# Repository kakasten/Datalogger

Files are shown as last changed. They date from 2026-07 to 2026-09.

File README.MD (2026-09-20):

# 🎲 Distributed Data Acquisition Platform for Race Vehicles

> A modular, scalable, engineering-driven architecture for high-performance vehicle instrumentation.







---

## 📖 Overview

This project is the development of a **distributed data acquisition platform** for race vehicles, designed to provide a modular, scalable, and easy-to-maintain architecture — capable of evolving continuously alongside the team's needs.

Built for **Formula SAE** vehicles, the system acquires data from analog, digital, frequency, and CAN sensors, transmits the information over a **CAN** network, and centralizes logging, processing, and telemetry in the Master module.

Unlike traditional systems, which centralize all instrumentation in a single acquisition unit, this platform adopts an architecture composed of one **Master module** and **multiple Slave modules**, distributed throughout the vehicle and placed close to the sensors they monitor.

**Key features:**

- ✅ Distributed acquisition
- ✅ CAN Bus communication
- ✅ Modular hardware
- ✅ Local data logging
- ✅ Telemetry support
- ✅ Fault isolation
- ✅ Expandable architecture

> More than a conventional datalogger, this is an open hardware, firmware, and documentation ecosystem, built to grow alongside the team.

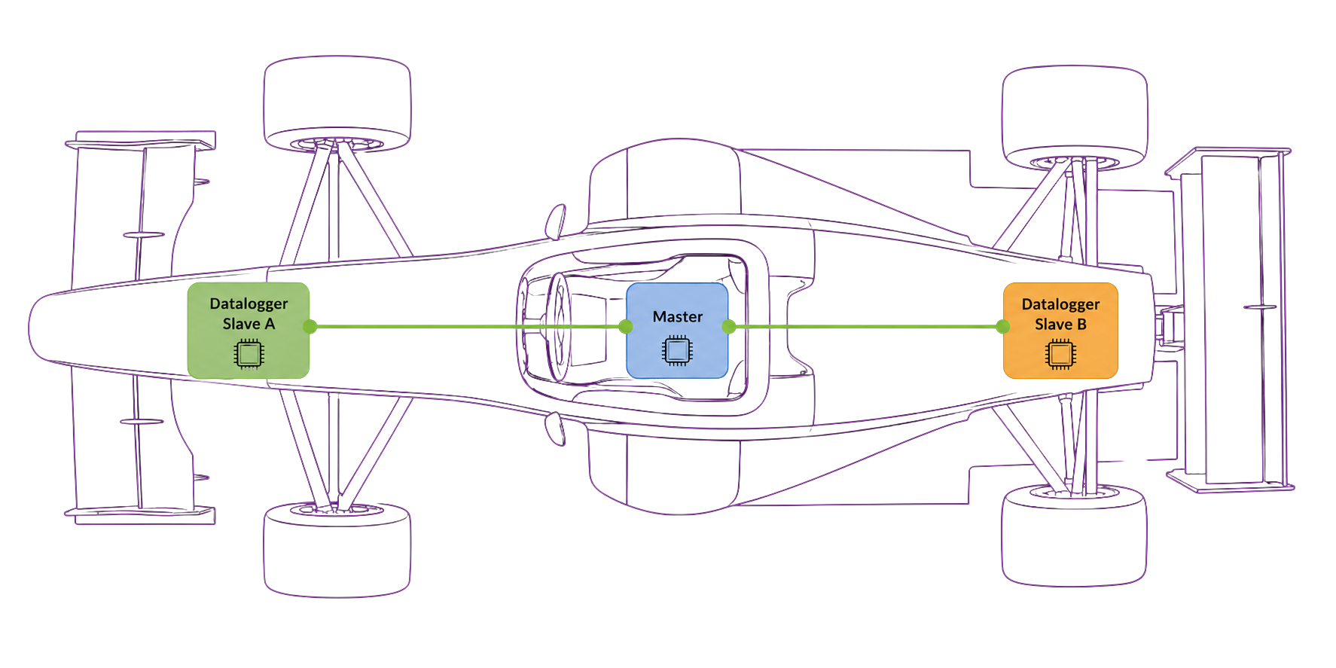
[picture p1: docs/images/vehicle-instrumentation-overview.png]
Vehicle Instrumentation Overview


---

## 🎯 The Problem We Solve

Centralized acquisition systems have well-known limitations in race vehicles:

- **Long, complex wiring harnesses**, with dozens of meters of cable running across the vehicle to a single central unit
- **High susceptibility to electromagnetic noise**, since low-amplitude analog signals must travel long distances before being conditioned
- **Difficult maintenance and expansion**, since every new sensor requires running a new cable to the central unit
- **Low scalability**, since expansion capacity is limited by the number of physical inputs on the central unit

Our approach solves these problems by **bringing processing to the sensor**, rather than the other way around.

---

## 🧩 System Architecture

### Selected Processing Units

The current hardware definition uses the following processing units:

| System role | Component | Responsibility |
| --- | --- | --- |
| Master | **Milk-V DUO S** (MPU) | High-level processing, data logging, telemetry, and system management |
| Slave | **STM32G431C8T6TR** (MCU) | Local sensor acquisition, signal processing, and CAN communication |

The platform is organized into two core functional blocks:

### 🔹 Master Module

The Master module is the platform's **central management point**. Its responsibilities include:

- Coordinating communication between the modules distributed across the vehicle
- Synchronizing data acquisition across all Slave modules
- Storing the data logged during vehicle operation
- Making data available to external analysis and development tools

The Master's architecture is designed to be **independent of specific implementation technologies** — allowing different software solutions, operating systems, communication protocols, or storage formats to be adopted as the project evolves, without compromising the platform's overall organization.

In the current implementation, the Master runs on the **Milk-V DUO S**, the selected **MPU (Microprocessor Unit)**, using an **RTOS (Real-Time Operating System)** as its software framework, responsible for coordinating logging, processing, and telemetry tasks.

### 🔹 Slave Modules

Slave modules are responsible for **local acquisition** of signals coming from the sensors. Close to the signal source, each module performs:

- Signal conditioning and filtering
- Analog-to-digital conversion
- Initial data processing
- Delivery of processed data to the vehicle's communication network

Each Slave is built around the **STM32G431C8T6TR**, the selected **MCU (Microcontroller Unit)**, responsible for local acquisition and for communicating over the **CAN** bus, which connects all modules to the Master.

Each module can be **specialized** according to the type of signal it needs to acquire:

| Module Type | Application |
| --- | --- |
| High-precision analog inputs | Pressure, temperature, potentiometer sensors |
| Digital inputs | On/off signals, buttons, limit switches |
| Timer capture | Wheel speed, RPM |
| Inertial sensors (IMU) | Acceleration, gyroscope |
| Suspension position | Vertical travel, suspension stroke |
| Custom modules | Application-specific sensors |

This specialization allows **hardware to be optimized for each module's function**, reducing cost, simplifying the electronic design, and increasing overall system reliability.

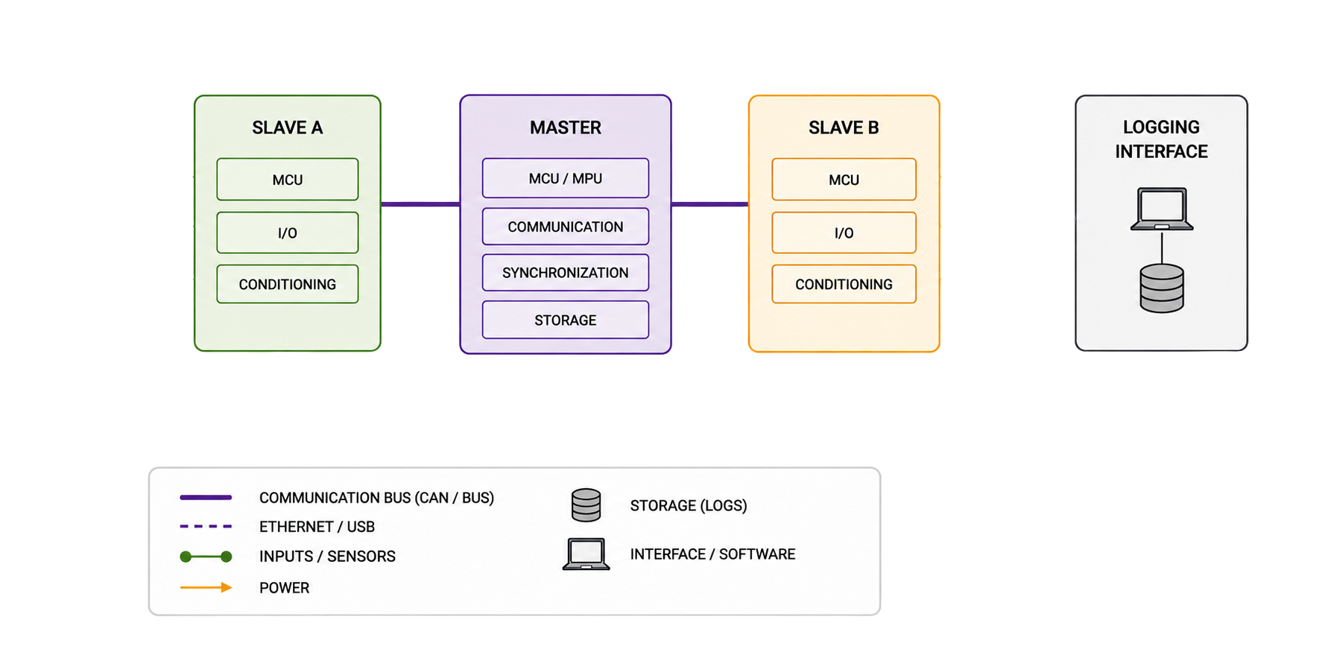
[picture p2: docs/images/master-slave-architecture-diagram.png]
Master and Slave Module Architecture Diagram


### 🔄 Communication Topology (High-Level View)

```text
                              ┌────────────────────────────┐
                              │           Master           │
                              │            MPU             │
                              │     RTOS • Data Logging    │
                              └────────────┬───────────────┘
                                           │
                                       CAN Network
                                           │
                 ┌─────────────────────────┴───────────────────────┐
                 │                                                 │
      ┌──────────▼──────────┐                           ┌──────────▼──────────┐
      │       Slave A       │                           │       Slave B       │
      │         MCU         │                           │         MCU         │
      │ Analog • Digital IO │                           │ Analog • Digital IO │
      └──────────┬──────────┘                           └──────────┬──────────┘
                 │                                                 │
          Vehicle Sensors                                   Vehicle Sensors
```

### 📊 Data Flow

1. Sensors generate raw electrical signals
2. Slave modules acquire and condition these signals locally
3. Measurements are transmitted over the **CAN** bus
4. The Master receives all messages from the network
5. Data is logged and, optionally, transmitted via real-time telemetry

### 🔗 Communication Architecture

Each communication interface is chosen based on bandwidth, latency, reliability, and hardware requirements:

- **CAN Bus** — the system's backbone, connecting the Master to one or more Slave modules
- **I²C / SPI / UART** — local interfaces between each module (Master or Slave) and its directly connected peripherals/sensors

```text
                              ┌─────────────────────────┐
                              │         Master          │
                              │           MPU           │
                              └────────────┬────────────┘
                                           │
                                      CAN Network
                                           │
                 ┌─────────────────────────┴───────────────────────┐
                 │                                                 │
      ┌──────────▼──────────┐                           ┌──────────▼──────────┐
      │       Slave A       │                           │       Slave B       │
      │         MCU         │                           │         MCU         │
      └──────────┬──────────┘                           └──────────┬──────────┘
                 │                                                 │
          I²C • SPI • UART                                  I²C • SPI • UART
                 │                                                 │
          Vehicle Sensors                                   Vehicle Sensors
```

---

## 🔌 Wiring Example

One of the main gains of the distributed architecture is the **drastic reduction in wiring harness complexity**. Instead of long individual cables running from each sensor to a central unit, each Slave module sits close to its own set of sensors, and only a shared communication bus runs across the vehicle.

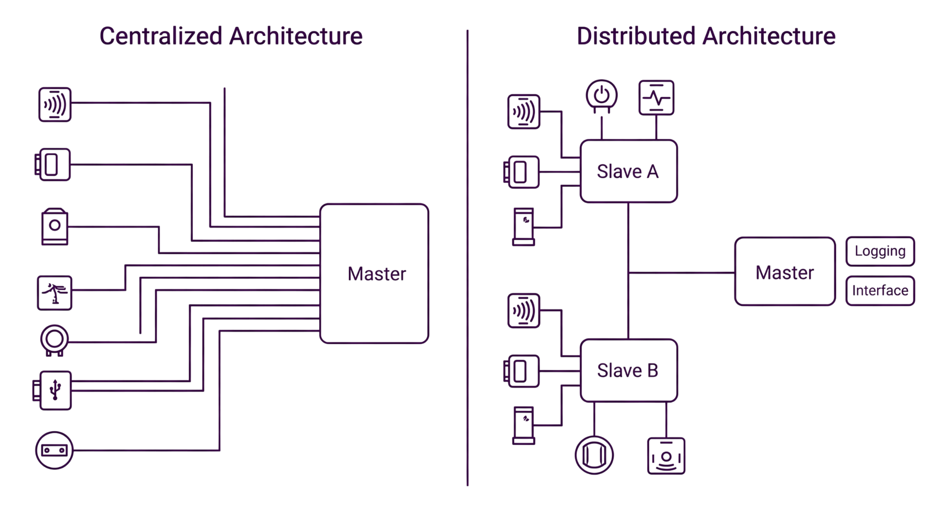
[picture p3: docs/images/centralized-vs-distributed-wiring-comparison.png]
Centralized vs. Distributed Wiring Comparison


**Conceptual comparison:**

| Aspect | Centralized System | Distributed System (this project) |
| --- | --- | --- |
| Total cable length | High | Reduced |
| Noise susceptibility | High (long analog signal runs) | Low (signal digitized close to source) |
| Ease of maintenance | Low | High |
| Scalability | Limited | High (just add a new module to the bus) |

---

## ⚙️ Engineering Philosophy

Since its inception, the project has prioritized a **clear separation between hardware, firmware, and development infrastructure**. Each component is developed as an independent module with well-defined interfaces, which ensures:

- ♻️ **Code reuse** across different modules and projects
- 🔧 **Simplified maintenance**, since each part can be modified independently
- 📈 **Easier future expansion**, without needing to restructure the entire platform
- 🔀 **Coexistence of hardware versions**, allowing gradual evolution without breaking compatibility

### 📚 Documented Engineering

More than a source code repository, this project is meant to be a **complete record of the engineering behind its development**. From the earliest stages, we aim to document:

- Architecture decisions and their technical rationale
- Functional diagrams and schematics
- Communication flows between modules
- Hardware version history
- Validation procedures and experimental results

This approach turns the repository into a **technical knowledge base**, valuable both for current developers and for future generations of the team.

---

## 🚀 Why Support This Project

This project goes beyond a one-off telemetry system — it represents an **investment in reusable engineering infrastructure**:

- **Common foundation for multiple applications**: rather than a one-off solution, the platform serves as a foundation for different instrumentation systems, from low-frequency measurements to high-speed signals requiring precise timing
- **Technical development for the team**: development spans embedded hardware, firmware, communication protocols, software engineering, and technical documentation — high-value skills for team members
- **Visibility and branding**: the project's public, well-structured documentation serves as a technical showcase for sponsors and partners
- **Continuity**: the emphasis on documentation and modularity ensures that today's investment keeps generating value across future generations of the system

Companies and sponsors interested in supporting the project can get in touch through the channels listed in the [Contact](#-contact) section.

---

## 🤝 Contributing

Contributions are welcome! To propose improvements, fixes, or new features:

1. Fork this repository
2. Create a branch for your change (`git checkout -b feature/feature-name`)
3. Commit your changes (`git commit -m 'Add new feature'`)
4. Push to the remote repository (`git push origin feature/feature-name`)
5. Open a Pull Request

---

## 📬 Contact

For questions, partnerships, or sponsorship proposals, get in touch with the team:

- **Email:** _luizfernandosilveriofelisbino@gmail.com_

---

## 📄 License

This project is distributed under the **[Apache License 2.0](LICENSE)**.

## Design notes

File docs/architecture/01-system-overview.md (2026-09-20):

# System Overview

## Purpose

The Datalogger system is a modular data acquisition platform designed for Formula SAE vehicles. It acquires data from vehicle sensors through distributed acquisition modules (Slaves), transmits the data over a CAN network, and centralizes logging, processing, and telemetry in the Master module.

---

## System Objectives

* Acquire data from analog, digital, frequency, and CAN sensors.
* Provide a modular and scalable hardware architecture.
* Minimize wiring complexity by distributing sensor acquisition.
* Ensure reliable communication between all modules.
* Store synchronized vehicle data for post-processing.
* Support real-time telemetry and diagnostics.

---

## Selected Processing Units

| System role | Component | Responsibility |
| --- | --- | --- |
| Master | **Milk-V DUO S** (MPU) | High-level processing, data logging, telemetry, and system management |
| Slave | **STM32G431C8T6TR** (MCU) | Local sensor acquisition, signal processing, and CAN communication |

---

## System Components

The system is composed of two primary modules:

* Master
* Slave

Each Slave is responsible for acquiring sensors located near its installation point, while the Master is responsible for coordinating the system, logging data, and interfacing with external devices.

---

## High-Level Architecture

```text
                              ┌────────────────────────────┐
                              │           Master           │
                              │      Milk-V DUO S (MPU)   │
                              │     ROS 2 • Data Logging   │
                              │         Telemetry          │
                              └────────────┬───────────────┘
                                           │
                                       CAN Network
                                           │
                 ┌─────────────────────────┴───────────────────────┐
                 │                                                 │
      ┌──────────▼──────────┐                           ┌──────────▼──────────┐
      │       Slave A       │                           │       Slave B       │
      │ STM32G431C8T6TR MCU │                           │ STM32G431C8T6TR MCU │
      │ Analog • Digital IO │                           │ Analog • Digital IO │
      └──────────┬──────────┘                           └──────────┬──────────┘
                 │                                                 │
          Vehicle Sensors                                   Vehicle Sensors
```

---

## Data Flow

1. Sensors generate electrical signals.
2. Slave modules acquire and condition the signals.
3. Measurements are transmitted over the CAN bus.
4. The Master receives all messages.
5. Data is logged and optionally transmitted via telemetry.

---

## Main Features

* Distributed acquisition
* CAN-based communication
* Modular hardware
* ROS 2 software architecture
* Local data logging
* Telemetry support
* Fault isolation
* Expandable architecture

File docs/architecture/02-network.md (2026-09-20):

# Communication Architecture

## Objective

Describe the communication architecture of the Datalogger system, including the communication interfaces used between modules and peripherals.

---

## Overview

The Datalogger system uses multiple communication interfaces to connect distributed acquisition modules, sensors, and external devices. Each interface is selected according to bandwidth, latency, reliability, and hardware requirements.

The CAN bus serves as the system backbone, connecting the Master module to one or more Slave modules. Local peripherals communicate directly with each module using dedicated interfaces such as I²C, SPI, and UART.

---

## Communication Topology

```text
                              ┌─────────────────────────┐
                              │         Master          │
                              │           MPU           │
                              └────────────┬────────────┘
                                           │
                                      CAN Network
                                           │
                 ┌─────────────────────────┴───────────────────────┐
                 │                                                 │
      ┌──────────▼──────────┐                           ┌──────────▼──────────┐
      │       Slave A       │                           │       Slave B       │
      │         MCU         │                           │         MCU         │
      └──────────┬──────────┘                           └──────────┬──────────┘
                 │                                                 │
          I²C • SPI • UART                                  I²C • SPI • UART
                 │                                                 │
          Vehicle Sensors                                   Vehicle Sensors
```

---

## Communication Interfaces

| Interface | Purpose | Scope |
| --- | --- | --- |
| CAN | Communication between Master and Slave modules | System |
| I²C | Local communication with peripherals | Local |
| SPI | High-speed peripheral communication | Local |
| UART | Point-to-point communication with external devices | Local |
| Ethernet  | Development and high-speed communication | External |
| USB | Programming, debugging and maintenance | External |

---

## CAN Network

The preliminary message count, priority classes, and identifier allocation are defined in the [CAN Bus Budget](07-can-bus-budget.md). That document is the baseline for implementation and must be updated whenever message rates, payloads, or node count change.

### CAN Purpose

The CAN bus is the primary communication channel of the Datalogger system.

### CAN Responsibilities

* Master ↔ Slave communication
* Sensor data transmission
* Configuration messages
* Diagnostics
* System status

### CAN Characteristics

* Multi-drop topology
* Differential signaling
* High reliability
* Fault tolerant
* Real-time communication

---

## I²C

### I²C Purpose

Provides communication with low-speed peripherals located on each module.

### I²C Typical Devices

* ADCs
* GPIO expanders
* I²C multiplexers
* Environmental sensors

---

## SPI

### SPI Purpose

Provides high-speed communication with local peripherals.

### SPI Typical Devices

* High-speed ADCs
* External memory
* Displays

---

## UART

### UART Purpose

Provides point-to-point communication with external devices.

### UART Typical Devices

* GNSS receivers
* IMUs
* Debug interfaces

---

## Ethernet

### Ethernet Purpose

Provides a high-speed interface for development and data transfer.

### Ethernet Typical Applications

* ROS 2 communication
* Software deployment
* Data download
* Remote diagnostics

---

## USB

### USB Purpose

Provides direct access for programming, debugging, and maintenance.

### USB Typical Applications

* Firmware upload
* Debugging
* Serial console
* Device configuration

---

## Communication Principles

The communication architecture follows these principles:

* Distributed data acquisition
* Standard communication interfaces
* Modular design
* Fault isolation
* Scalable architecture
* Reliable real-time communication

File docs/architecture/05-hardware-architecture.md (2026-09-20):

# Hardware Architecture

## Objective

Describe the hardware architecture of the Datalogger system, including the responsibilities of each hardware module, sensor acquisition, signal conditioning, power distribution, and hardware interfaces.

---

## Overview

The Datalogger hardware is organized into distributed acquisition modules connected to a central Master module.

The Master provides the main processing and data management capabilities, while the Slave modules are responsible for acquiring vehicle sensor signals close to their physical installation points.

This distributed architecture reduces sensor wiring length, simplifies the integration of vehicle sensors, and allows the acquisition system to scale according to the requirements of the vehicle.

---

## System Hardware

The system is composed of two main hardware roles:

* Master
* Slave

The Master is based on the **Milk-V DUO S**, the selected Microprocessor Unit (MPU), while each Slave uses the **STM32G431C8T6TR**, the selected Microcontroller Unit (MCU), for local sensor acquisition and processing.

```text
                           ┌────────────────────────────┐
                           │          MASTER            │
                           │      Milk-V DUO S (MPU)   │
                           │                            │
                           │  Processing                │
                           │  Data Logging              │
                           │  Telemetry                 │
                           │  System Management         │
                           └────────────┬───────────────┘
                                        │
                                   CAN Network
                                        │
                  ┌─────────────────────┴─────────────────────┐
                  │                                           │
       ┌──────────▼──────────┐                    ┌──────────▼──────────┐
       │       SLAVE A       │                    │       SLAVE B       │
       │ STM32G431C8T6TR MCU │                    │ STM32G431C8T6TR MCU │
       │                     │                    │                     │
       │ Signal Acquisition  │                    │ Signal Acquisition  │
       │ Signal Conditioning │                    │ Signal Conditioning │
       │ Local Processing    │                    │ Local Processing    │
       └──────────┬──────────┘                    └──────────┬──────────┘
                  │                                           │
           Vehicle Sensors                             Vehicle Sensors
```

---

## Master Module

### Master Purpose

The Master is the central processing and data management module of the Datalogger system.

### Master Responsibilities

* Receive data from Slave modules
* Process and manage acquired data
* Store vehicle data
* Manage system-level services
* Provide telemetry interfaces
* Provide external communication interfaces
* Coordinate system operation

### Master Hardware

The Master hardware is composed of:

* Milk-V DUO S (MPU)
* Non-volatile storage
* CAN interface
* Ethernet interface
* USB interface
* Power management
* External communication interfaces

---

## Slave Module

### Slave Purpose

The Slave is a distributed sensor acquisition module responsible for acquiring and conditioning signals from vehicle sensors.

Multiple Slave modules can be deployed throughout the vehicle according to sensor location and acquisition requirements.

### Slave Responsibilities

* Acquire analog signals
* Acquire digital signals
* Measure frequency-based signals
* Perform signal conditioning
* Convert analog signals to digital measurements
* Perform local signal processing
* Transmit measurements to the Master
* Monitor local hardware status

### Slave Hardware

Each Slave is composed of:

* STM32G431C8T6TR (MCU)
* ADC interfaces
* Signal conditioning circuits
* Digital input interfaces
* Frequency measurement interfaces
* CAN interface
* Local communication interfaces
* Power regulation and protection

---

## Sensor Acquisition

The Datalogger supports multiple types of vehicle sensor signals.

| Signal Type | Typical Application | Acquisition Module |
| --- | --- | --- |
| Analog | Pressure, temperature, potentiometers | Slave |
| Digital | Switches, status signals | Slave |
| Frequency | Wheel speed, rotational sensors | Slave |
| CAN | Vehicle ECUs and smart sensors | Master / Slave |
| I²C | Local digital sensors | Slave |

The acquisition hardware is designed to adapt the electrical characteristics of the vehicle sensors to the voltage and signal requirements of the MCU and peripheral devices.

---

## Signal Conditioning

Signal conditioning is performed locally within the Slave modules whenever possible.

Typical conditioning stages include:

```text
Vehicle Sensor
      │
      ▼
Protection
      │
      ▼
Signal Conditioning
      │
      ▼
Filtering
      │
      ▼
ADC / Digital Input
      │
      ▼
MCU
      │
      ▼
CAN Network
```

Signal conditioning may include:

* Overvoltage protection
* Input protection
* Voltage level adaptation
* Analog filtering
* Signal buffering
* Pull-up / pull-down networks
* Frequency signal conditioning

The specific conditioning circuit depends on the electrical characteristics of each sensor.

---

## Power Architecture

Power distribution is separated according to the requirements of the vehicle, sensors, and electronics.

The hardware architecture provides dedicated power domains for:

* Vehicle input power
* Sensor power
* Digital electronics
* Analog electronics
* Communication interfaces

The detailed power distribution and regulation strategy is documented separately in the Power Architecture document.

---

## Hardware Interfaces

The main hardware interfaces are:

| Interface | Hardware Role | Typical Usage |
| --- | --- | --- |
| CAN | Inter-module communication | Master ↔ Slave |
| I²C | Local peripheral interface | ADCs and sensors |
| SPI | High-speed peripheral interface | Memory and ADCs |
| UART | Point-to-point interface | GNSS, IMU, debug |
| Ethernet  | External high-speed interface | Development and data transfer |
| USB | External service interface | Debugging and maintenance |

The communication behavior and protocol-level definitions are described in the Communication Architecture document.

---

## Modularity

The hardware architecture is designed to allow modules to be added or modified without requiring major changes to the rest of the system.

Each Slave operates as an independent acquisition unit with a defined interface to the system.

This allows:

* Additional Slave modules
* Different sensor configurations
* Hardware revisions
* Independent module testing
* Reuse of acquisition hardware
* Simplified vehicle integration

---

## Hardware Design Principles

The hardware architecture follows these principles:

* Distributed sensor acquisition
* Modular hardware
* Short sensor wiring
* Local signal conditioning
* Electrical protection
* Clear separation of responsibilities
* Scalable number of acquisition modules
* Design for maintainability
* Design for testing
* Automotive-oriented robustness

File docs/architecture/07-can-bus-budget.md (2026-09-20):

# CAN Bus Budget

## Objective

Define the preliminary CAN bus budget for the Datalogger, including the expected message set, message priorities, and identifier allocation. This document is a baseline for firmware and hardware implementation and must be refined after the sensor list and timing requirements are finalized.

---

## Scope and Assumptions

The preliminary budget uses the following assumptions:

- The CAN bus connects one Master (Milk-V DUO S) to multiple Slave modules.
- Slaves use the STM32G431C8T6TR and support CAN FD.
- Standard 11-bit CAN identifiers are used.
- The identifier value determines arbitration priority: lower values have higher priority.
- The initial network target is up to 8 Slave modules.
- The initial nominal arbitration rate is 500 kbit/s.
- CAN FD data-phase configuration and payload sizes remain to be validated during bus-load testing.
- Message frequencies are preliminary engineering limits, not final sensor sampling rates.

The bus budget must be recalculated if the number of Slaves, message frequencies, payload sizes, or CAN bit rates change.

---

## Priority Classes

| Priority | Class | Use | Identifier range |
| --- | --- | --- | --- |
| P0 | Emergency and safety | Emergency events, watchdog, bus-critical faults | `0x000–0x07F` |
| P1 | Synchronization and control | Time synchronization, acquisition commands, operating state | `0x080–0x0FF` |
| P2 | High-rate acquisition | Fast sensor measurements and time-critical feedback | `0x100–0x1FF` |
| P3 | Normal acquisition | Standard analog, digital, and frequency measurements | `0x200–0x3FF` |
| P4 | Diagnostics and configuration | Health, configuration, identification, and diagnostics | `0x400–0x5FF` |
| P5 | Development and reserved | Development traffic and future extensions | `0x600–0x6FF` |

Identifiers from `0x700–0x7FF` are reserved for future use and must not be assigned without updating this document.

---

## Preliminary Identifier Map

The source field identifies the module that produces the message. The initial allocation supports module addresses `0x0–0xF`, allowing up to 16 addressed modules. `S` represents the Slave address.

| Identifier | Message | Direction | Frequency limit | Payload | Priority |
| --- | --- | --- | ---: | ---: | --- |
| `0x010` | Emergency event | Master / Slave → network | Event-driven | 8 bytes | P0 |
| `0x020 + S` | Slave watchdog/status fault | Slave → Master | Event-driven, max. 10 Hz | 8 bytes | P0 |
| `0x080` | Network time synchronization | Master → Slaves | 100 Hz | 8 bytes | P1 |
| `0x090` | Acquisition control | Master → Slaves | 50 Hz | 8 bytes | P1 |
| `0x0A0 + S` | Slave operating state | Slave → Master | 10 Hz | 8 bytes | P1 |
| `0x100 + S` | High-rate measurement group 0 | Slave → Master | 1 kHz | 16 bytes FD | P2 |
| `0x110 + S` | High-rate measurement group 1 | Slave → Master | 500 Hz | 16 bytes FD | P2 |
| `0x200 + S` | Analog measurement group 0 | Slave → Master | 100 Hz | 16 bytes FD | P3 |
| `0x210 + S` | Analog measurement group 1 | Slave → Master | 100 Hz | 16 bytes FD | P3 |
| `0x220 + S` | Digital and frequency inputs | Slave → Master | 100 Hz | 8 bytes | P3 |
| `0x230 + S` | Sensor status and timestamps | Slave → Master | 100 Hz | 16 bytes FD | P3 |
| `0x400 + S` | Slave health and diagnostics | Slave → Master | 1 Hz | 16 bytes FD | P4 |
| `0x410 + S` | Configuration response | Slave → Master | Event-driven | 16 bytes FD | P4 |
| `0x480` | Configuration command | Master → Slave | Event-driven | 16 bytes FD | P4 |
| `0x490` | Firmware/service command | Master → Slave | Event-driven | 16 bytes FD | P4 |
| `0x600` | Development trace | Master / Slave → network | Development only | 16 bytes FD | P5 |

For a given message family, `S` is the Slave address from `0x0` to `0xF`. The resulting identifier must remain inside the range assigned to that family.

---

## Preliminary Message Count

For the initial target of 8 Slaves, the periodic traffic budget is:

| Message family | Messages per Slave | Network total | Frequency per message | Aggregate rate |
| --- | ---: | ---: | ---: | ---: |
| Operating state | 1 | 8 | 10 Hz | 80 messages/s |
| High-rate group 0 | 1 | 8 | 1,000 Hz | 8,000 messages/s |
| High-rate group 1 | 1 | 8 | 500 Hz | 4,000 messages/s |
| Analog group 0 | 1 | 8 | 100 Hz | 800 messages/s |
| Analog group 1 | 1 | 8 | 100 Hz | 800 messages/s |
| Digital/frequency inputs | 1 | 8 | 100 Hz | 800 messages/s |
| Sensor status/timestamps | 1 | 8 | 100 Hz | 800 messages/s |
| Diagnostics | 1 | 8 | 1 Hz | 8 messages/s |
| **Total periodic traffic** | **8** | **64** | — | **15,288 messages/s** |

The high-rate rows are a capacity placeholder for the fastest acquisition use cases. They must not be enabled for every Slave until the bus-load calculation and measurements confirm that the selected bit rates provide sufficient margin.

Event-driven emergency, configuration, and service messages are excluded from the periodic total. Their maximum rates must be bounded by the firmware implementation.

---

## Bus-Load Budget

The preliminary design target is:

- Normal operating bus load: **≤ 50%**.
- Sustained worst-case bus load: **≤ 70%**.
- Emergency and diagnostic traffic must retain arbitration access under normal load.
- At least 30% capacity should remain for timing variation, retransmissions, future messages, and additional Slaves.

Bus load must be calculated using the complete on-wire frame size, including arbitration, control, CRC, acknowledgment, inter-frame spacing, bit stuffing, and the selected nominal/data bit rates. Payload byte count alone is not sufficient for this calculation.

The current message-rate table is therefore a message-count budget, not a validated utilization result.

---

## Allocation Rules

1. Lower CAN identifiers always represent higher arbitration priority.
2. Emergency and safety messages must use the P0 range.
3. Periodic sensor messages must include a source Slave address in their identifier.
4. A message family must keep the same payload layout and cycle time across all Slaves.
5. Event-driven messages must define rate limiting and timeout behavior in the protocol specification.
6. Identifier reuse is not allowed while two message types can coexist on the bus.
7. New identifiers must be added to this map before implementation.
8. Any change to message frequency or payload size requires repeating the bus-load calculation.

---

## Open Items

The following items remain to be defined before the CAN budget can be considered final:

- Final CAN nominal and data-phase bit rates.
- Exact number and type of sensors per Slave.
- Final sampling frequencies and required latency for each signal.
- Payload encoding, byte order, scaling, and timestamp format.
- Maximum number of Slaves in the vehicle.
- Bus termination and physical-layer validation.
- Measured bus load under nominal and worst-case traffic.
- Fault handling, retransmission, timeout, and node-offline behavior.

---

## Related Documentation

- [Communication Architecture](02-network.md)
- [Hardware Architecture](05-hardware-architecture.md)
- [ADR-001: Distributed Datalogger Architecture](../getting-started/ADR-001-distributed-datalogger-architecture.md)

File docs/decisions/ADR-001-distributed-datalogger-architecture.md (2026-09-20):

# ADR-001: Distributed Datalogger Architecture

## Status

Accepted

## Context

The Datalogger system needs to acquire data from multiple sensors distributed throughout the vehicle.

A centralized architecture would require most sensors to be connected directly to a single processing unit. This would increase the amount of wiring throughout the vehicle and concentrate sensor acquisition, processing, and communication responsibilities in one location.

The system should provide:

* Scalable sensor acquisition
* Reduced wiring complexity
* Deterministic data acquisition
* Reliable communication between modules
* Easy expansion for additional sensors
* Separation between sensor acquisition and high-level data processing
* Independent development and testing of acquisition modules

Two main architectures were considered:

1. **Centralized architecture** — all sensors are connected directly to a single Master.
2. **Distributed architecture** — sensor acquisition is divided between multiple Slave modules connected to a central Master.

## Decision

The Datalogger will use a **distributed architecture** composed of:

* A **Master** responsible for high-level processing, data aggregation, storage, and external communication.
* Multiple **Slaves** responsible for local sensor acquisition, signal conditioning, preprocessing, and communication with the Master.
* A communication bus connecting the Master and Slaves.

Each Slave will be positioned according to the physical distribution and requirements of the sensors it handles.

The number and exact placement of Slaves will be defined based on sensor distribution, wiring requirements, acquisition requirements, and communication bandwidth.

## Alternatives Considered

### Centralized Architecture

All sensors would be connected directly to the Master.

**Advantages:**

* Simpler logical architecture
* Fewer electronic modules
* Centralized firmware

**Disadvantages:**

* Large amount of wiring throughout the vehicle
* Longer sensor connections
* More complex harness
* Less modular sensor acquisition
* Greater concentration of I/O requirements in the Master

### Distributed Architecture

Sensors are divided between multiple Slave modules connected to the Master.

**Advantages:**

* Reduced sensor wiring
* Modules can be positioned close to their sensors
* Modular hardware
* Easier expansion
* Separation of acquisition and high-level processing
* Easier reuse of Slave designs

**Disadvantages:**

* More electronic modules
* Requires a communication network
* Requires synchronization and communication management
* Increased firmware complexity

## Consequences

### Positive

* The system can scale by adding additional Slave modules.
* Sensor wiring can be significantly reduced by placing Slaves near their respective sensors.
* Sensor acquisition responsibilities are distributed across multiple modules.
* Hardware and firmware can be developed and tested in modular units.
* Different Slave configurations can support different sensor subsystems.

### Negative

* The communication network becomes a critical part of the architecture.
* Additional hardware is required for each Slave.
* Firmware must handle communication, synchronization, configuration, and fault detection between modules.
* The system requires careful management of communication bandwidth and message priorities.

## Related Decisions

This decision will influence subsequent ADRs, including:

* Master MPU selection
* Slave MCU selection
* Communication protocol selection
* CAN bus bandwidth and message architecture
* Slave physical distribution
* Sensor acquisition architecture
* Power architecture
* Firmware architecture
* Slave configuration architecture

## Notes

This ADR defines the high-level system architecture. Specific implementation details and component selections should be documented in separate ADRs or architecture documents.

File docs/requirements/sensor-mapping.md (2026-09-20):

# Sensor Mapping

## Objective

Define the mapping between vehicle sensors, physical subsystems, and Datalogger Slave modules.

This document is used to define which sensors are connected to each Slave and where each Slave is physically located in the vehicle.

The mapping should consider:

* Physical sensor location
* Sensor type and interface
* Required acquisition rate
* Number of required inputs
* Wiring distance
* Slave hardware capabilities
* Communication requirements

## Sensor Mapping

| Subsystem | Sensor | Quantity | Interface | Slave | Location |
| --- | --- | ---: | --- | ----- | --- |
| Front Left | Wheel Speed | 1 | Frequency | TBD | Front Left Wheel  |
| Front Right | Wheel Speed | 1 | Frequency | TBD | Front Right Wheel |
| Rear Left | Wheel Speed | 1 | Frequency | TBD | Rear Left Wheel |
| Rear Right | Wheel Speed | 1 | Frequency | TBD | Rear Right Wheel  |
| Steering | Steering Angle | 1 | Analog | TBD | Steering Column |
| Front Suspension | Suspension Position | 2 | Analog | TBD | Front Suspension  |
| Rear Suspension  | Suspension Position | 2 | Analog | TBD | Rear Suspension |
| Braking | Brake Pressure | 2 | Analog | TBD | Brake System |
| Vehicle Dynamics | IMU | 1 | TBD | TBD | Vehicle Center |
| Aerodynamics | Pitot | 1 | I2C / Digital | TBD | Vehicle Front |

> The sensor list is preliminary and should be updated as the vehicle sensor requirements are defined.

## Slave Distribution

The Datalogger will use multiple Slave modules distributed throughout the vehicle.

Each Slave should be assigned to a physical subsystem where practical, reducing sensor wiring and simplifying local acquisition.

The final number and physical placement of Slaves will be determined based on:

* Sensor distribution
* Required I/O
* Wiring length
* Power distribution
* CAN bus topology
* Hardware constraints

### Slave 1

**Location:** TBD
**Subsystem:** TBD

| Sensor | Quantity | Interface |
| --- | ---: | --- |
| TBD | TBD | TBD |

### Slave 2

**Location:** TBD
**Subsystem:** TBD

| Sensor | Quantity | Interface |
| --- | ---: | --- |
| TBD | TBD | TBD |

## Mapping Rules

The following rules should be considered when assigning sensors to Slaves:

1. Sensors should preferably be connected to the physically closest Slave.
2. High-frequency signals should be considered when determining Slave placement.
3. Sensors requiring specialized interfaces should be assigned to Slaves with the required peripherals.
4. The number of sensors assigned to a Slave must remain within its available I/O and processing capacity.
5. Communication bandwidth must be considered when distributing high-rate signals.
6. Critical signals should have appropriate fault detection and communication handling.
7. The mapping should remain modular so that additional sensors or Slaves can be added without major architectural changes.

## Open Questions

* [ ] Define complete vehicle sensor list
* [ ] Define physical location of each sensor
* [ ] Define number of Slaves
* [ ] Define physical location of each Slave
* [ ] Assign each sensor to a Slave
* [ ] Verify Slave I/O capacity
* [ ] Verify CAN bandwidth requirements
* [ ] Verify power distribution requirements

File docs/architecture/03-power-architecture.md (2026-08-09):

# Power Architecture

## Objective

Describe the power architecture of the Datalogger system, including power input, distribution, regulation, protection, and the main power domains used by the hardware.

---

## Overview

The Datalogger system is powered from the vehicle electrical system. The incoming vehicle supply is distributed through protected and regulated power stages to provide the voltage levels required by the Master, Slave modules, sensors, and peripheral devices.

The power architecture separates vehicle power, sensor power, and sensitive electronic power domains to improve system reliability and reduce the impact of electrical noise.

---

## System Power Architecture

```text
                         Vehicle Power
                              │
                              │
                       ┌──────▼──────┐
                       │    Input    │
                       │ Protection  │
                       └──────┬──────┘
                              │
                         Power Input
                              │
              ┌───────────────┴───────────────┐
              │                               │
       ┌──────▼──────┐                 ┌──────▼──────┐
       │    Master   │                 │    Slave    │
       │ Power Stage │                 │ Power Stage │
       └──────┬──────┘                 └──────┬──────┘
              │                               │
       ┌──────┴──────┐                ┌───────┴────────┐
       │             │                │                │
    Digital       Peripheral       Digital          Sensors
    Power           Power           Power            Power
       │             │                │                │
      MPU        Interfaces           MCU        Analog / Digital
```

---

## Power Domains

The system is divided into several power domains according to the requirements of each subsystem.

| Power Domain | Purpose | Typical Loads |
| --- | --- | --- |
| Vehicle Input | Primary system supply | Master and Slave modules |
| Digital Power | Digital electronics | MPU, MCU, digital ICs |
| Analog Power | Low-noise analog circuits | ADCs, signal conditioning |
| Sensor Power | Vehicle sensors | Pressure, temperature, position sensors |
| Communication Power | Communication interfaces  | CAN, Ethernet, USB |
| Peripheral Power | Local peripherals | Displays, memory, external devices |

---

## Input Power

The vehicle electrical system provides the primary power source for the Datalogger.

The input power stage is responsible for protecting the electronics against electrical disturbances present in the vehicle power network.

Typical protection functions include:

* Reverse polarity protection
* Overvoltage protection
* Transient protection
* Overcurrent protection
* Input filtering

The exact protection implementation is defined in the corresponding hardware design documentation.

---

## Power Regulation

The vehicle input voltage is converted into regulated voltage rails required by the system.

```text
Vehicle Input
     │
     ▼
Input Protection
     │
     ▼
Voltage Conversion
     │
     ├──────────► Digital Power
     │
     ├──────────► Analog Power
     │
     └──────────► Sensor Power
```

Voltage conversion stages are selected according to the required output voltage, current capability, efficiency, thermal performance, and electrical noise requirements.

---

## Master Power

The Master contains its own power regulation and distribution stages.

The Master power system provides regulated power to:

* MPU
* Storage
* CAN interface
* Ethernet interface
* USB interface
* Other local peripherals

The Master power architecture is designed to support the computational and communication requirements of the central processing module.

---

## Slave Power

Each Slave contains local power regulation and distribution.

The Slave power system provides power to:

* MCU
* ADCs
* Signal conditioning circuits
* Communication interfaces
* Vehicle sensors
* Local peripherals

Local regulation allows each Slave to operate as an independent acquisition module and reduces the need to distribute multiple regulated voltages throughout the vehicle.

---

## Sensor Power

Sensor power is distributed locally by the Slave modules whenever practical.

This approach reduces wiring complexity and allows sensor power requirements to be managed independently for each acquisition module.

Sensor power may include dedicated voltage rails for different sensor types and electrical requirements.

---

## Analog and Digital Power

Analog and digital circuits are treated as separate power domains where required.

Analog power is intended for noise-sensitive circuits such as:

* ADCs
* Operational amplifiers
* Analog signal conditioning
* Precision references

Digital power is used for:

* MCUs
* MPUs
* Digital communication interfaces
* Logic circuits

The separation of these domains helps reduce digital switching noise coupling into analog measurements.

---

## Power Distribution Principles

The power architecture follows these principles:

* Protected vehicle power input
* Local voltage regulation
* Separation of analog and digital power domains
* Dedicated sensor power distribution
* Modular power architecture
* Protection against automotive electrical disturbances
* Adequate current and thermal margins
* Minimized noise coupling
* Independent operation of acquisition modules

---

## Detailed Power Design

Detailed information about regulators, protection devices, voltage rails, current requirements, component selection, and PCB power routing is documented in the corresponding Master and Slave hardware documentation.

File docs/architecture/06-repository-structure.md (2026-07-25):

# Repository Organization

## Objective

Define the repository structure of the Datalogger project and describe the purpose of each directory.

---

## Repository Structure

```text
amp-datalogger/
│
├── README.md
│
├── docs/
│   ├── requirements/
│   │   ├── system.md
│   │   ├── master.md
│   │   ├── slave.md
│   │   └── ate.md
│   │
│   ├── architecture/
│   │   ├── 01-system-overview.md
│   │   ├── 02-network.md
│   │   ├── 03-power-architecture.md
│   │   ├── 04-software-architecture.md
│   │   ├── 05-hardware-architecture.md
│   │   └── 06-repository-structure.md
│   │
│   ├── interfaces/
│   │   ├── can.md
│   │   ├── i2c.md
│   │   ├── spi.md
│   │   └── uart.md
│   │
│   ├── decisions/
│   │   ├── ADR-0001-...
│   │   └── ADR-0002-...
│   │
│   └── diagrams/
│
├── commons/
│   └── hardware/
│       └── kicad/
│
├── master/
│
├── slave/
│
└── ate/
```

---

## Directory Description

### README.md

Entry point of the repository. Provides a high-level description of the project and links to the available documentation.

---

### docs/

Contains all engineering documentation related to the project.

---

### docs/requirements/

System and subsystem requirements.

Examples:

- System requirements
- Master requirements
- Slave requirements
- ATE requirements

---

### docs/architecture/

High-level system architecture documentation.

Includes:

- System overview
- Hardware architecture
- Software architecture
- Communication architecture
- Power architecture
- Repository organization

---

### docs/interfaces/

Defines communication interfaces used throughout the project.

Examples:

- CAN
- I²C
- SPI
- UART

Each document specifies the interface purpose, configuration, and design guidelines.

---

### docs/decisions/

Architecture Decision Records (ADRs).

Each ADR documents an important engineering decision, including its motivation, alternatives, and consequences.

---

### docs/diagrams/

Stores architecture and system diagrams in editable and exported formats.

Examples:

- Draw.io
- SVG
- PNG
- PDF

---

### commons/

Contains resources shared across multiple projects in the repository.

This directory is intended for reusable assets that are not specific to a single module.

Current contents:

- Shared KiCad symbol libraries
- Shared KiCad footprint libraries
- KiCad project templates

As the project evolves, additional shared resources may be added while keeping them independent from the Master, Slave, and ATE projects.

---

### master/

Contains all files related to the Master module.

Typical contents include:

- Hardware
- Firmware
- Documentation
- Manufacturing files

---

### slave/

Contains all files related to the Slave module.

Typical contents include:

- Hardware
- Firmware
- Documentation
- Manufacturing files

---

### ate/

Contains the Automated Test Equipment (ATE) project.

Typical contents include:

- Test hardware
- Test software
- Test procedures
- Validation reports

---

## Organization Principles

The repository organization follows these principles:

- Separation of concerns
- Modular development
- Independent documentation
- Version-controlled engineering artifacts
- Easy navigation and maintenance

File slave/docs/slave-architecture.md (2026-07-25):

# Datalogger Slave Architecture

| Field | Description  |
| --- | --- |
| Module | Slave |
| Document Type | Architecture |
| Status | Draft |
| Version | 0.1 |

---

## Objective

Define the hardware and software architecture of the Datalogger Slave module.

This document describes the internal organization of the Slave, including power distribution, sensor acquisition, processing, communication interfaces, and expansion capabilities.

The Slave is designed as a distributed data acquisition module focused on reliable automotive sensor acquisition and CAN communication.

---

## System Overview

The Datalogger Slave is an embedded acquisition unit responsible for collecting data from multiple vehicle sensors, performing local signal processing, and transmitting measurements through the CAN network.

The Slave architecture is divided into the following main subsystems:

* Power Management
* Sensor Interface
* Signal Conditioning
* Processing Unit
* Communication Interface
* Diagnostics and Debug
* Expansion Interfaces

---

## High-Level Architecture

```text
                 Vehicle Power
                      |
                    12V
                      |
              +----------------+
              | Power Management |
              +----------------+
                 |          |
                5V         3.3V
                 |          |
        +--------+----------+--------+
        |                         |
 Sensor Supply              Processing Unit
        |                         |
 Sensors                  +--------------+
        |                 | MCU          |
        |                 |              |
        |                 | ADC          |
        |                 | Timers       |
        |                 | CAN          |
        |                 +--------------+
        |
 Signal Conditioning
        |
 CAN Network <---------- CAN Transceiver
```

---

## Power Architecture

### Input Stage

The Slave receives power from the vehicle electrical system.

Input:

* 12 V nominal supply

The input stage provides protection against automotive electrical conditions.

Required blocks:

* Reverse polarity protection
* Overcurrent protection
* Input filtering
* Transient voltage protection

---

## Voltage Regulation

The power system generates the required internal rails.

### 5 V Rail

Purpose:

* Sensor excitation
* Analog circuits
* External peripherals

Requirements:

* Buck conversion from 12 V
* Current protection
* Filtering

---

### 3.3 V Rail

Purpose:

* MCU
* Digital logic
* Communication circuits

Requirements:

* Low-noise regulation
* Decoupling capacitors
* Stable operation during load variation

---

## Sensor Interface Architecture

The Slave supports different sensor types through dedicated input stages.

---

## Analog Acquisition

Architecture:

```text
Sensor
  |
Protection
  |
Filtering
  |
Voltage Conditioning
  |
ADC
  |
MCU
```

Supported sensors:

* Pressure sensors
* Temperature sensors
* Potentiometers
* Position sensors

Characteristics:

* Automotive voltage range support
* Noise filtering
* ADC-compatible voltage levels

---

## Digital Inputs

Architecture:

```text
Digital Sensor
      |
Protection
      |
Filtering
      |
GPIO / Interrupt
      |
MCU
```

Used for:

* Switches
* Digital sensors
* Status signals

Requirements:

* Electrical protection
* Noise immunity
* Configurable input levels

---

## Frequency Inputs

Architecture:

```text
Pulse Sensor
      |
Protection
      |
Signal Conditioning
      |
Timer Capture
      |
MCU
```

Used for:

* Wheel speed sensors
* Hall sensors
* Encoders

Requirements:

* Accurate timing measurement
* Interrupt/timer capture capability

---

## Processing Architecture

### Microcontroller

The MCU is responsible for:

* Sensor acquisition
* Data processing
* Communication management
* Diagnostics
* Fault monitoring

Required peripherals:

| Peripheral | Purpose |
| --- | --- |
| ADC | Analog measurements |
| Timers | Frequency measurement |
| CAN | Network communication |
| GPIO | Digital signals |
| UART | Debug/configuration |
| I2C | Expansion |
| SPI | Expansion |
| SWD | Programming/debug |

---

## Communication Architecture

### CAN Interface

CAN is the primary communication interface.

Architecture:

```text
MCU CAN Peripheral
        |
 CAN Transceiver
        |
 CAN Bus
```

Responsibilities:

* Sensor data transmission
* Slave status messages
* Diagnostic information
* Configuration messages

Target:

* CAN 500 kbps

---

## Expansion Interfaces

The Slave provides additional interfaces for future hardware expansion.

### I2C Interface

Purpose:

* External sensors
* Auxiliary ADCs
* Monitoring devices

Characteristics:

* Low-speed peripherals
* Multiple devices possible

---

### SPI Interface

Purpose:

* High-speed peripherals
* External ADCs
* Memory devices

Characteristics:

* Higher bandwidth than I2C
* Short-distance communication

---

### UART Interface

Purpose:

* Firmware debugging
* Configuration
* Development interface

---

## Diagnostics Architecture

The Slave must provide mechanisms for monitoring its own operation.

### Hardware Monitoring

Includes:

* Power status
* MCU activity
* CAN communication status

---

### Fault Detection

The system should monitor:

* Supply voltage
* Communication errors
* MCU failures
* Sensor acquisition faults

---

## Firmware Architecture

The firmware should be organized into independent layers.

```text
Application Layer
        |
Sensor Management
        |
Hardware Abstraction Layer
        |
MCU Drivers
        |
Hardware
```

---

## Application Layer

Responsible for:

* Sensor scheduling
* Data formatting
* Communication management

---

## Sensor Layer

Responsible for:

* Sensor drivers
* Calibration
* Filtering
* Validation

---

## Hardware Abstraction Layer

Responsible for:

* ADC
* GPIO
* Timers
* Communication peripherals

---

## PCB Architecture Guidelines

The PCB should follow these principles:

### Analog / Digital Separation

Analog acquisition circuits should be separated from:

* Switching regulators
* CAN communication
* Digital clocks

---

### Protection Placement

Protection components should be placed close to connectors:

* TVS diodes
* Filtering components
* Input protection

---

### Debug Access

The PCB should include:

* SWD connector
* UART header
* Test points

---

## Design Principles

The Slave architecture follows these principles:

* Modular sensor acquisition
* Automotive robustness
* Expandability
* Simple debugging
* Minimal unnecessary hardware
* Clear separation between acquisition and processing

---

## Future Extensions

Possible future additions:

* External ADC modules
* Additional CAN channels
* More sensor interfaces
* Local data buffering
* Advanced diagnostics

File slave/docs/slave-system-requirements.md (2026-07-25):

# Datalogger Slave System Requirements

## Objective

Define the hardware and functional requirements for the Datalogger Slave board.

The goal is to establish the minimum required features for the first Slave PCB design, focusing on reliable sensor acquisition and communication while avoiding unnecessary complexity.

---

## Slave Overview

The Datalogger Slave is a distributed data acquisition module responsible for:

* Reading vehicle sensors
* Conditioning sensor signals
* Processing measurements locally
* Communicating acquired data through CAN
* Monitoring its own hardware status

The Slave should be designed as a robust acquisition module, not as a control unit.

---

## Functional Requirements

## Sensor Acquisition

The Slave must support multiple types of automotive sensors.

### Analog Inputs

Required:

* Measurement range compatible with automotive sensors
* Support for automotive voltage signals (0-12 V) through input conditioning circuits
* Input protection
* Analog filtering before ADC

Examples:

* Pressure sensors
* Temperature sensors
* Potentiometers
* Position sensors

Initial target:

* 8 to 10 analog inputs

---

### Digital Inputs

Required:

* Reading external digital signals
* Protection against electrical noise
* Configurable input levels

Examples:

* Switches
* Digital sensors
* Status signals

Initial target:

* 4 to 8 digital inputs

---

### Frequency Inputs

Required for sensors that provide pulse signals.

Examples:

* Wheel speed sensors
* Hall sensors
* Encoders

Requirements:

* Timer capture support
* Frequency measurement
* Input filtering

---

## Outputs

Outputs are not required for the first Slave version.

The initial objective is data acquisition.

Not included:

* PWM outputs
* Actuator control
* High-current outputs

These can be considered in future revisions if required.

---

## Power System

### Input Supply

The Slave receives:

* 12 V vehicle supply

Required protections:

* Reverse polarity protection
* Input filtering
* Transient protection

---

## Power Rails

### 5 V Supply

Used for:

* External sensors
* Analog circuits

Requirements:

* Buck converter from 12 V
* Current protection
* Filtering

---

### 3.3 V Supply

Used for:

* Microcontroller
* Digital logic
* Communication circuits

Requirements:

* Stable regulation
* Filtering
* Decoupling

---

### Sensor Supply

The Slave should provide regulated sensor supply outputs.

Requirements:

* 5 V sensor supply
* Current protection
* Filtering
* Monitoring capability

Examples:

* Pressure sensors
* Potentiometers
* Temperature sensors

---

## Communication

### Interface Requirements

The Slave board must provide hardware interfaces for sensor acquisition, communication, debugging, and future expansion.

| Interface | Purpose | Required | Notes |
| --- | --- | --- | --- |
| CAN | Main communication interface | Yes | Communication with external modules, 500 kbps target |
| ADC | Analog sensor acquisition | Yes | Internal or external ADC, 0-5 V / 0-12 V conditioned inputs |
| GPIO | Digital inputs and status signals | Yes | Protected automotive digital inputs |
| Timer Input Capture | Frequency measurement | Yes | Wheel speed, Hall sensors, encoder signals |
| I2C | External sensor expansion | Yes | Low-speed sensors, ADCs, temperature sensors |
| SPI | High-speed peripherals expansion  | Optional | External ADCs, memory, communication devices |
| UART | Debug and external communication  | Yes | Firmware debugging and configuration |
| SWD/JTAG | Programming and debugging | Yes | MCU programming and real-time debugging |
| PWM | Output control | No | Not required in first revision |

---

## CAN Interface

The Slave communicates through CAN.

Requirements:

* CAN controller/interface
* CAN transceiver
* ESD protection
* Automotive noise robustness
* Termination resistor

Target:

* CAN 500 kbps

---

## Microcontroller Requirements

The MCU must support:

Required peripherals:

* ADC
* CAN
* Timers
* GPIO interrupts
* UART/SPI/I2C
* Debug interface
* Watchdog

---

## Diagnostics and Safety

The Slave should provide monitoring mechanisms for system reliability.

### Status Monitoring

Required indicators:

* Power status LED
* MCU status LED
* CAN communication/error LED

---

### Protection Features

Required:

* Power input protection
* Supply filtering
* ESD protection
* Watchdog monitoring
* Reset circuit

---

## PCB Requirements

The PCB should include:

* Clear separation between analog and digital sections
* Test points for critical signals
* Debug connector
* Expandable GPIO
* Reliable automotive connectors

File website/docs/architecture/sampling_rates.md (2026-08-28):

# Sampling Rates

## Objective

This document defines the acquisition, processing and communication rates for the Datalogger.

The goal is not to maximize the sampling frequency. The goal is to select, for each signal, the **lowest practical rate that preserves the information required for vehicle analysis**, while remaining deterministic and compatible with the sensor, MCU, CAN bus and storage system.

The design therefore separates four different concepts:

1.  **Physical bandwidth** — how quickly the measured phenomenon can meaningfully change.
2.  **Acquisition rate** — how often the Slave samples or updates the signal.
3.  **Processing rate** — how often filtering, estimation and control-oriented calculations execute.
4.  **CAN transmission rate** — how often the processed information is transmitted to the vehicle network.

These rates do not have to be equal.

* * *

## 1\. Design Methodology

### 1.1 Physical signal bandwidth

Every measurement has a useful bandwidth. The bandwidth is not necessarily the same as the maximum frequency generated by the sensor interface.

For example, a wheel-speed sensor may generate hundreds of pulses per second, but the quantity of interest is wheel rotational speed. The pulse frequency determines the requirements of the **input-capture hardware**, while the required wheel-speed update rate is determined by vehicle dynamics and the temporal resolution required to identify events such as wheel slip or wheel lock.

The design therefore distinguishes:

```text
Physical phenomenon
       |
       +--> useful signal bandwidth
       |
       +--> critical transient duration
       |
       +--> sensor/interface bandwidth
```

### 1.2 Nyquist-Shannon theorem

For a band-limited signal with highest relevant frequency `f_max`, uniform sampling requires:

$$
 f_s > 2f_{max}
$$

The theoretical Nyquist minimum is therefore:

$$
f_{Nyquist}=2f_{max}
$$

This is a **necessary condition**, not a complete engineering specification.

Sampling exactly at the Nyquist limit leaves no useful transition band for a real anti-aliasing filter and gives poor temporal resolution for transient analysis. The final sampling rate must therefore also consider the required event resolution.

### 1.3 Transient-resolution criterion

For an event with characteristic duration `T_event`, the number of acquired samples is:

$$
N_{event}=f_sT_{event}
$$

Therefore, if the design requires at least `N_req` samples during an event:

$$
f_s \geq \frac{N_{req}}{T_{event}}
$$

This criterion is particularly important for:

- wheel lock and wheel slip;
- brake-pressure buildup;
- suspension impacts;
- rapid steering input;
- transient acceleration and yaw response.

Nyquist determines whether the frequency content can be represented. The transient criterion determines whether the **time history is resolved sufficiently for engineering analysis**.

### 1.4 Filtering

Analog signals must be filtered before ADC conversion to prevent unwanted high-frequency content from aliasing into the measurement band.

The anti-aliasing filter must satisfy the relationship between:

$$
f_{signal},\quad f_{filter},\quad \frac{f_s}{2}
$$

The filter transition band must fit below the Nyquist frequency. A practical design should therefore not place the desired signal bandwidth directly at `f_s/2`.

Digital filtering can subsequently be used for:

- noise reduction;
- smoothing;
- estimation;
- downsampling;
- feature extraction.

Digital filtering **cannot recover information that was already lost by undersampling**.

### 1.5 Safety / engineering margin

A final sampling rate should be higher than the strict theoretical minimum when:

- the signal bandwidth is uncertain;
- the anti-aliasing filter is non-ideal;
- multiple sensors must be time-correlated;
- short transients are important;
- the rate is inexpensive for the MCU;
- the sensor/interface provides additional bandwidth.

The margin is therefore selected from the complete system requirement rather than applying an arbitrary multiplier to every sensor.

***

## 2\. System-Level Initial Rates

The following values are the **initial engineering targets** for the Datalogger.

| Signal | Acquisition | Processing | CAN | Primary reason |
| --- | ---: | ---: | ---: | --- |
| Wheel Speed | **1 kHz** | 1 kHz | **200 Hz** | 1 ms temporal resolution + wheel-speed transients |
| Steering Angle | **200 Hz** | 200 Hz | **100 Hz** | Fast driver input and cross-sensor correlation |
| Suspension Position | **500 Hz** | 500 Hz | **200 Hz** | Suspension transients and wheel-hop |
| IMU | **400 Hz** | 400 Hz | **400 Hz** | VN-300 output-rate limit and inertial bandwidth |
| Brake Pressure | **1 kHz** | 1 kHz | **200 Hz** | Fast pressure transients and brake/wheel correlation |
| Temperatures | **20 Hz** | 10 Hz | **10 Hz** | Thermal time constants are much slower |
| Pitot Tube | **100 Hz** | 100 Hz | **50 Hz** | Airspeed dynamics and sensor update margin |

These are not arbitrary values. Each section below derives the rate from physical behavior, timing requirements, sensor limits and system cost.

> **Important:** Wheel Speed, Steering, Suspension and Brake Pressure rates are architecture targets until the final sensor models and measured vehicle data are available. The document deliberately does not treat estimated physical bandwidths as immutable facts.

***

## 3\. Sensor Acquisition Rates

### 3.1 Wheel Speed

#### 3.1.1 What must be measured?

The objective is not to reconstruct the electrical waveform of the wheel sensor. The objective is to obtain a sufficiently fast estimate of wheel rotational speed to analyze:

- braking;
- wheel lock;
- traction loss;
- wheel spin;
- wheel-to-wheel speed differences;
- wheel-hop-related variation.

The raw sensor signal should therefore be measured using **timer input capture** whenever possible.

For a pulse train:

$$
T_{pulse}=t_n-t_{n-1}
$$

and:

$$
f_{pulse}=\frac{1}{T_{pulse}}
$$

For `PPR` pulses per revolution:

$$
RPM=\frac{60f_{pulse}}{PPR}
$$

The wheel speed is then calculated from wheel circumference.

#### 3.1.2 Maximum pulse frequency

For wheel diameter `D`, vehicle speed `v` and `PPR` pulses/revolution:

$$
f_{pulse}=\frac{v}{\pi D}PPR
$$

Example with `D = 0.50 m`, `v = 120 km/h = 33.33 m/s`:

$$
f_{pulse}=\frac{33.33}{\pi(0.50)}PPR
$$

Therefore:

| PPR | Pulse frequency at 120 km/h |
| ---: | ---: |
| 10  | 212 Hz |
| 20  | 424 Hz |
| 40  | 849 Hz |
| 48  | 1.02 kHz |
| 60  | 1.27 kHz |

This calculation is **not** the sampling-rate requirement of the wheel-speed variable. It is the requirement on the digital input/timer path.

The final PPR and loaded wheel diameter must be inserted once the wheel-speed sensor is finalized.

#### 3.1.3 Braking event

Consider the reference event:

$$
80\ km/h\rightarrow50\ km/h
$$

in:

$$
1\ s
$$

The average deceleration is:

$$
v_0=22.22\ m/s
$$

$$
v_1=13.89\ m/s
$$

$$
a=\frac{13.89-22.22}{1}\approx-8.33\ m/s^2
$$

At different rates:

| Rate | Period | Samples in 1 s | Samples in 5 ms | Samples in 10 ms |
| ---: | ---: | ---: | ---: | ---: |
| 100 Hz | 10 ms | 101 | 0.5 | 1 |
| 200 Hz | 5 ms | 201 | 1 | 2 |
| 500 Hz | 2 ms | 501 | 2.5 | 5 |
| **1 kHz** | **1 ms** | **1001** | **5** | **10** |
| 2 kHz | 0.5 ms | 2001 | 10  | 20  |

If wheel lock develops over approximately 5–10 ms, 100 Hz cannot resolve the event adequately: it gives between 0.5 and 1 sample over the event.

At 1 kHz, the same event contains 5–10 samples. This makes the onset, slope and timing of the wheel-speed deviation measurable rather than relying on a single sample transition.

#### 3.1.4 Why not 2 kHz?

2 kHz would provide more temporal resolution, but doubles the acquisition workload compared with 1 kHz.

For the intended vehicle analysis, 1 ms resolution already provides 5 samples in a 5 ms event and 10 samples in a 10 ms event. Unless testing shows that relevant wheel-speed events contain meaningful dynamics below approximately 2.5 ms, the additional 2 kHz information is not justified by the current requirements.

Therefore:

$$
\boxed{f_{acq}=1\ kHz}
$$

The value should be re-evaluated if measured wheel-lock transients show significant sub-5 ms behavior.

#### 3.1.5 Processing

Wheel-speed processing should run at 1 kHz so that the latest timer-capture measurement can be converted and filtered with approximately 1 ms update resolution.

#### 3.1.6 CAN

Sending wheel speed at 1 kHz for all four wheels would be unnecessarily expensive on a 500 kbit/s CAN bus.

Instead, the Slave keeps the high-rate measurement locally and transmits a lower-rate processed representation.

Initial CAN rate:

$$
\boxed{f_{CAN}=200\ Hz}
$$

The four wheel speeds should preferably be packed into one CAN frame rather than four independent frames.

* * *

### 3.2 Steering Angle

#### 3.2.1 Physical behavior

Steering is a human input, so its useful bandwidth is much lower than the IMU or wheel-speed pulse signal. However, the Datalogger must correlate steering input with the resulting yaw rate, lateral acceleration and suspension response.

The critical requirement is therefore not only Nyquist bandwidth but also **cross-sensor timing resolution**.

#### 3.2.2 Candidate rates

Consider a fast steering event lasting 50 ms:

| Rate | Samples in 50 ms |
| ---: | ---: |
| 50 Hz | 2.5 |
| 100 Hz | 5 |
| **200 Hz** | **10** |
| 500 Hz | 25  |

At 50 Hz, a fast steering transient is represented by only 2–3 points. At 200 Hz, it is represented by approximately 10 points.

This is valuable when comparing steering input against yaw-rate and lateral-acceleration response.

#### 3.2.3 Nyquist

The exact steering bandwidth must ultimately be measured from the vehicle data. If a maximum relevant frequency `f_max` is identified, the theoretical minimum is:

$$
f_s>2f_{max}
$$

The selected 200 Hz rate leaves a large margin for the expected low-frequency human input while keeping the acquisition inexpensive.

#### 3.2.4 Selection

$$
\boxed{f_{acq}=200\ Hz}
$$

$$
\boxed{f_{process}=200\ Hz}
$$

$$
\boxed{f_{CAN}=100\ Hz}
$$

200 Hz is selected because it provides 5 ms timing resolution for cross-channel analysis without imposing a significant ADC or CPU burden.

* * *

### 3.3 Suspension Position

#### 3.3.1 Physical behavior

Suspension position contains several dynamic components:

- body motion;
- suspension natural modes;
- unsprung-mass / wheel-hop dynamics;
- bump and curb impacts;
- rapid compression and rebound.

The previous engineering analysis identifies wheel-hop around 10–15 Hz and impact content around the 25 Hz region. These values should be validated experimentally rather than treated as exact limits. fileciteturn2file5L255-L264

#### 3.3.2 Nyquist

Using 25 Hz as the current design bandwidth:

$$
f_{Nyquist}=2(25)=50\ Hz
$$

100 Hz would satisfy Nyquist, but it gives only:

$$
\frac{100}{25}=4
$$

samples per 25 Hz cycle.

At 500 Hz:

$$
\frac{500}{25}=20
$$

samples per cycle.

#### 3.3.3 Impact resolution

Consider a 20 ms suspension transient:

| Rate | Samples in 20 ms |
| ---: | ---: |
| 100 Hz | 2 |
| 200 Hz | 4 |
| **500 Hz** | **10** |
| 1 kHz | 20  |

For suspension analysis, the distinction between compression and rebound can be important. 500 Hz provides 10 points over a 20 ms event while remaining well within the capability of the STM32G431 ADC architecture for analog channels.

#### 3.3.4 Selection

$$
\boxed{f_{acq}=500\ Hz}
$$

$$
\boxed{f_{process}=500\ Hz}
$$

$$
\boxed{f_{CAN}=200\ Hz}
$$

500 Hz is selected as a compromise between transient resolution and system cost. 1 kHz remains a possible test mode if experimental data demonstrates meaningful content that cannot be reconstructed at 500 Hz.

* * *

### 3.4 IMU

#### 3.4.1 Sensor-limited rate

The VN-300 is different from the analog sensors because its bandwidth and output rate are specified by the manufacturer.

The VN-300 specifies:

- accelerometer bandwidth: **230 Hz**;
- gyroscope bandwidth: **265 Hz**;
- IMU output rate: **up to 400 Hz**. citeturn0search36turn0search0

Therefore the rate cannot simply be increased arbitrarily.

For the accelerometer:

$$
f_{Nyquist}=2(230)=460\ Hz
$$

For the gyroscope:

$$
f_{Nyquist}=2(265)=530\ Hz
$$

However, the VN-300 used in this project provides IMU data at up to 400 Hz. 

This means the system cannot claim to preserve the full specified 230/265 Hz sensor bandwidth from a 400 Hz output stream. The sensor's own output-rate limitation must be considered when defining the usable acquisition bandwidth.

#### 3.4.2 Selection

$$
\boxed{f_{acq}=400\ Hz}
$$

$$
\boxed{f_{process}=400\ Hz}
$$

$$
\boxed{f_{CAN}=400\ Hz}
$$

400 Hz is selected because it is the specified maximum IMU output rate of the VN-300.

This is a stronger justification than selecting 500 Hz and then pretending the sensor can provide a 500 Hz measurement.

If a future IMU configuration with a higher output rate is selected, this section must be re-evaluated.

* * *

### 3.5 Brake Pressure

#### 3.5.1 Critical event

Brake pressure is important because it must be correlated with wheel-speed behavior during braking.

A representative rapid pressure ramp used for the engineering calculation is:

$$
0\rightarrow40\ bar
$$

in:

$$
150\ ms
$$

This produces an average pressure rate of:

$$
\frac{40}{0.15}\approx267\ bar/s
$$

#### 3.5.2 Resolution comparison

The pressure change between samples is approximately:

$$
\Delta P=267T_s
$$

| Rate | Period | Approx. pressure change/sample |
| ---: | ---: | ---: |
| 20 Hz | 50 ms | 13.3 bar |
| 100 Hz | 10 ms | 2.67 bar |
| 200 Hz | 5 ms | 1.33 bar |
| 500 Hz | 2 ms | 0.53 bar |
| **1 kHz** | **1 ms** | **0.267 bar** |

At 20 Hz, the measurement jumps more than 13 bar per sample. That is too coarse to accurately locate the pressure buildup.

At 200 Hz, the resolution is approximately 1.3 bar/sample, which is already useful.

At 1 kHz, the same ramp changes only approximately 0.27 bar between samples and is represented by:

$$
1000(0.15)=150
$$

samples.

#### 3.5.3 Correlation with wheel lock

If the wheel-speed system is sampled at 1 kHz, acquiring brake pressure at 1 kHz provides the same 1 ms time base.

This allows analysis of:

```text
Brake pressure
      |
      | pressure buildup
      v
Wheel speed deviation
      |
      | wheel lock / slip onset
      v
Vehicle deceleration
```

with a common 1 ms acquisition grid.

#### 3.5.4 Selection

$$
\boxed{f_{acq}=1\ kHz}
$$

$$
\boxed{f_{process}=1\ kHz}
$$

$$
\boxed{f_{CAN}=200\ Hz}
$$

The high-rate pressure measurement is kept locally for logging and event analysis. CAN carries the lower-rate processed value to avoid consuming the bus with redundant samples.

The final pressure-sensor response time must be checked against the selected 1 kHz rate. If the transducer itself has a response time much slower than 1 ms, the additional samples do not add physical information.

* * *

### 3.6 Temperatures

#### 3.6.1 Physical behavior

Temperature is fundamentally different from wheel speed, pressure and IMU measurements.

Thermal systems have comparatively long time constants because heat must be transferred through:

- the sensor package;
- mounting material;
- fluid or air;
- the measured component;
- surrounding structures.

The relevant quantity is therefore normally a thermal time constant rather than a high-frequency vibration bandwidth.

For a first-order thermal response:

$$
T(t)=T_{final}+(T_0-T_{final})e^{-t/\tau}
$$

where `τ` is the thermal time constant.

The frequency-domain corner associated with this first-order system is:

$$
f_c=\frac{1}{2\pi\tau}
$$

#### 3.6.2 Example

If a temperature sensor has an effective thermal time constant of 0.5 s:

$$
f_c=\frac{1}{2\pi(0.5)}\approx0.32\ Hz
$$

Even a 20 Hz acquisition rate would provide:

$$
\frac{20}{0.32}\approx62
$$

samples per thermal corner cycle.

Therefore, a 20 Hz acquisition target is already heavily oversampled for a typical thermal response.

#### 3.6.3 Selection

Because the final temperature sensor and mounting configuration determine the actual thermal time constant, the exact rate must be validated experimentally.

Initial target:

$$
\boxed{f_{acq}=20\ Hz}
$$

$$
\boxed{f_{process}=10\ Hz}
$$

$$
\boxed{f_{CAN}=10\ Hz}
$$

This rate is intentionally conservative for temperature acquisition while avoiding unnecessary high-rate logging of slowly changing quantities.

* * *

### 3.7 Pitot Tube

#### 3.7.1 Physical behavior

The Pitot system measures differential pressure and converts it to airspeed.

The relevant vehicle-level dynamics are much slower than wheel-speed or IMU transients. However, the sensor's own output rate and response time must also be considered.

The current design target is 100 Hz acquisition so that a 10 ms time base is available for acceleration and braking analysis without making the Pitot channel a high-rate data consumer.

#### 3.7.2 Vehicle acceleration example

Consider:

$$
50\ km/h\rightarrow100\ km/h
$$

in:

$$
2\ s
$$

At 100 Hz:

$$
N=100(2)=200
$$

samples.

The average airspeed change between samples is:

$$
\Delta v=\frac{50}{200}=0.25\ km/h
$$

This is already fine temporal resolution for vehicle-level airspeed analysis.

At 50 Hz the change is 0.5 km/h/sample, still useful, but 100 Hz gives additional margin for sensor dynamics and cross-correlation.

#### 3.7.3 Selection

$$
\boxed{f_{acq}=100\ Hz}
$$

$$
\boxed{f_{process}=100\ Hz}
$$

$$
\boxed{f_{CAN}=50\ Hz}
$$

The final MS4525DO configuration must be checked against its selected digital output mode and actual response/update rate before freezing this requirement. The manufacturer provides the MS4525DO datasheet as the authoritative source for the selected part. urlMS4525DO documentationturn1search0

* * *

## 4\. Processing Rates

Acquisition and processing are related but not necessarily identical.

The processing rate is selected according to what the algorithm needs.

| Signal | Acquisition | Processing | Reason |
| --- | ---: | ---: | --- |
| Wheel Speed | 1 kHz | 1 kHz | immediate wheel-speed update and slip detection |
| Steering | 200 Hz | 200 Hz | correlation with vehicle dynamics |
| Suspension | 500 Hz | 500 Hz | transient preservation before downsampling |
| IMU | 400 Hz | 400 Hz | preserve sensor output stream |
| Brake Pressure | 1 kHz | 1 kHz | pressure/wheel correlation |
| Temperature | 20 Hz | 10 Hz | thermal signal is slow |
| Pitot | 100 Hz | 100 Hz | pressure-to-speed conversion and filtering |

### 4.1 Filtering and downsampling

High-rate acquisition allows the Slave to perform filtering before reducing the rate for CAN.

For example:

```text
Brake Pressure
      |
      | 1 kHz acquisition
      v
Anti-alias / signal conditioning
      |
      v
Digital filtering
      |
      +----> 1 kHz local log
      |
      +----> 200 Hz CAN
```

The same architecture can be used for wheel speed and suspension position.

The downsampling factor must be chosen only after filtering. Directly dropping samples can cause aliasing.

* * *

## 5\. CAN Transmission Rates

### 5.1 Why CAN rate differs from acquisition rate

The Datalogger may need high-rate information internally without needing to transmit every sample over the vehicle CAN bus.

Therefore:

$$
f_{CAN}\leq f_{acq}
$$

for the initial architecture.

The high-rate data can be retained locally, while CAN carries:

- current values;
- filtered values;
- status;
- diagnostic information;
- event flags;
- lower-rate telemetry.

### 5.2 Initial CAN rates

| Signal | Acquisition | CAN | Reduction |
| --- | ---: | ---: | ---: |
| Wheel Speed | 1000 Hz | 200 Hz | 5:1 |
| Steering | 200 Hz | 100 Hz | 2:1 |
| Suspension | 500 Hz | 200 Hz | 2.5:1 |
| IMU | 400 Hz | 400 Hz | 1:1 |
| Brake Pressure | 1000 Hz | 200 Hz | 5:1 |
| Temperature | 20 Hz | 10 Hz | 2:1 |
| Pitot | 100 Hz | 50 Hz | 2:1 |

The reduction is intentional. The acquisition system preserves the higher-rate data; CAN is optimized for network-wide availability.

* * *

## 6\. Rate Allocation / CAN Budget

### 6.1 CAN assumptions

Initial network assumptions:

- Classical CAN;
- nominal bitrate: **500 kbit/s**;
- standard 11-bit identifier;
- maximum 8-byte payload per frame;
- planning frame length: approximately **128 bits nominal** and up to approximately **150 bits** under conservative bit-stuffing assumptions.

For planning:

$$
T_{frame,nominal}=\frac{128}{500000}=256\ \mu s
$$

$$
T_{frame,worst}\approx\frac{150}{500000}=300\ \mu s
$$

The exact frame length depends on identifier, data length, bit stuffing and frame format. The 150-bit value is therefore a **budgeting approximation**, not a universal exact CAN frame length.

### 6.2 Message packing

CAN budget must be calculated from **frames**, not individual physical signals.

The preferred architecture is to pack signals with compatible rates into common frames.

For example:

```text
Wheel Speed Frame
+--------------------------------+
| FL | FR | RL | RR | status    |
+--------------------------------+
```

This is preferable to four independent CAN frames.

Similarly:

```text
Brake Frame
+--------------------------------+
| Front Pressure | Rear Pressure |
+--------------------------------+
```

and suspension channels can be grouped into one or more frames.

### 6.3 Proposed packed-frame budget

An initial packed-frame architecture is:

| Frame group | Frames | CAN rate | Frame/s |
| --- | ---: | ---: | ---: |
| Wheel Speed | 1 | 200 Hz | 200 |
| Steering | 1 | 100 Hz | 100 |
| Suspension | 2 | 200 Hz | 400 |
| IMU | 2 | 400 Hz | 800 |
| Brake Pressure | 1 | 200 Hz | 200 |
| Pitot | 1 | 50 Hz | 50  |
| Temperature | 1 | 10 Hz | 10  |
| **Total** | **9** | | **1760 frames/s** |

Using the conservative 150-bit planning value:

$$
Load=1760\times\frac{150}{500000}
$$

$$
Load\approx52.8\%
$$

Using the nominal 128-bit estimate:

$$
Load=1760\times\frac{128}{500000}
$$

$$
Load\approx45.1\%
$$

This leaves substantial headroom for:

- other vehicle ECUs;
- diagnostic traffic;
- asynchronous events;
- future signals;
- retransmissions;
- changes in message packing.

### 6.4 Why sending every acquisition sample is not acceptable

If every physical signal were transmitted independently at its acquisition rate, the network would become saturated.

For example, using the six main sensor groups without temperature and assuming four wheel-speed channels, four suspension channels and two brake-pressure channels:

$$
4(1000)+1(200)+4(500)+2(400)+2(1000)+1(100)
$$

$$
=5700\ messages/s
$$

With 150 bits/frame:

$$
Load=5700\times\frac{150}{500000}
$$

$$
Load=171\%
$$

This is physically impossible on a 500 kbit/s bus.

The conclusion is not that the sensors must be sampled more slowly. The conclusion is that **high-rate acquisition and network transmission are different architectural requirements**.

### 6.5 Why packing matters

Without packing, four wheel-speed values at 200 Hz consume four frames per update:

$$
4\times200=800\ frames/s
$$

With packing, they consume one frame per update:

$$
1\times200=200\ frames/s
$$

The reduction is:

$$
\frac{800-200}{800}=75\%
$$

of the wheel-speed frame traffic.

Therefore, message packing is part of the sampling-rate architecture, not merely a later optimization.

* * *

## 7\. Storage Budget

Storage must be evaluated separately from CAN.

For a logged record containing `B` bytes:

$$
R_{data}=N_{records/s}B
$$

and for duration `T`:

$$
Storage=R_{data}T
$$

If the local logger stores all high-rate acquisition streams, the storage rate must be calculated from the actual logging record format.

For an illustrative 16-byte record:

#### Main high-rate streams

Approximate logical sample rate:

$$
4(1000)+1(200)+4(500)+2(400)+2(1000)+1(100)
$$

$$
=5700\ samples/s
$$

At 16 bytes/sample:

$$
5700(16)=91.2\ kB/s
$$

Approximately:

$$
91.2\times3600\approx328\ MB/h
$$

This is an architectural estimate, not the final file size. The final storage requirement depends on:

- timestamp width;
- record headers;
- compression;
- binary format;
- whether raw and processed data are both stored;
- whether CAN frames are logged separately.

The important point is that storage is feasible at these rates, but unnecessarily increasing every signal to several kHz would multiply the data volume without necessarily adding useful information.

* * *

## 8\. MCU / Acquisition Limitations

The STM32G431 is capable of high-rate acquisition. The device contains two 12-bit ADCs with up to 4 MSPS conversion rate at full resolution, plus DMA and timer peripherals suitable for deterministic acquisition. 

This does not mean that every channel can simply run at 4 MSPS. The complete acquisition chain must include:

- number of active ADC channels;
- ADC sampling time;
- source impedance;
- analog settling time;
- multiplexer settling;
- filtering;
- DMA transfers;
- CPU processing;
- FreeRTOS scheduling;
- memory bandwidth.

The relevant engineering constraint is:

$$
T_{available}>T_{conversion}+T_{transfer}+T_{processing}
$$

for every real-time acquisition path.

### 8.1 Interrupts

High-frequency acquisition should use hardware peripherals and DMA where possible.

A 1 kHz software interrupt for every analog sample is unnecessary if a timer-triggered ADC + DMA can fill a buffer autonomously.

Wheel Speed should use timer input capture rather than a high-rate software GPIO polling loop.

### 8.2 Timing determinism

A nominal frequency is not sufficient. The actual sampling interval should remain deterministic:

$$
T_s\approx constant
$$

Excessive CPU or bus load can introduce jitter. Therefore, a lower deterministic acquisition rate is preferable to a nominally higher rate that the firmware cannot sustain consistently.

* * *

## 9\. What Happens If Frequencies Are Increased Indiscriminately?

Increasing every channel to 10 kHz would produce far more data, but most channels would not contain useful information at that rate.

For example, increasing a 1 kHz wheel-speed acquisition to 10 kHz multiplies:

- timer-processing updates by 10;
- buffer traffic by 10;
- local data volume by 10;
- filtering workload by 10.

Unless measurements demonstrate relevant dynamics below the 1 ms scale, this provides little engineering benefit.

The correct design principle is therefore:

> **Use the highest rate justified by the required information, not the highest rate supported by the MCU.**

* * *

## 10\. Validation Plan

The frequencies in this document should be validated experimentally before being frozen as final requirements.

### 10.1 FFT / spectral validation

Record representative signals at the highest practical rate and calculate their spectra.

For each signal, determine:

$$
f_{useful,max}
$$

Then verify:

$$
f_{acq}>2f_{useful,max}
$$

with practical filtering margin.

### 10.2 Transient validation

For each critical event, measure the shortest relevant duration:

| Event | Required measurement |
| --- | --- |
| Wheel lock | wheel-speed divergence |
| Brake application | pressure buildup |
| Curb / bump | suspension displacement |
| Slalom | steering input |
| Hard braking | IMU acceleration / yaw response |
| Acceleration | Pitot / wheel speed |

Then calculate:

$$
N_{event}=f_sT_{event}
$$

The chosen rate should provide enough samples to identify the event reliably.

### 10.3 A/B sampling-rate test

When practical, compare recordings at:

- nominal rate;
- 2× nominal rate;
- 4× nominal rate.

If downsampling the high-rate recording to the nominal rate produces no meaningful loss in the quantities of interest, the nominal rate is supported experimentally.

### 10.4 Final acceptance criteria

A sampling rate should be considered final when:

1.  the sensor bandwidth is known;
2.  the anti-aliasing filter is defined;
3.  Nyquist is satisfied;
4.  critical transients have sufficient samples;
5.  the sensor/interface can sustain the rate;
6.  the MCU can sustain the rate deterministically;
7.  processing deadlines are satisfied;
8.  CAN utilization remains within the network budget;
9.  storage requirements are acceptable;
10. test data confirms that increasing the rate further does not provide meaningful information.

* * *

## 11\. Final Rate Allocation

| Sensor | Acquisition | Processing | CAN | Main justification |
| --- | ---: | ---: | ---: | --- |
| **Wheel Speed** | **1 kHz** | **1 kHz** | **200 Hz** | 1 ms resolution; 5 samples in a 5 ms event; timer capture handles raw pulse timing |
| **Steering Angle** | **200 Hz** | **200 Hz** | **100 Hz** | 5 ms resolution for driver-input / vehicle-response correlation |
| **Suspension Position** | **500 Hz** | **500 Hz** | **200 Hz** | 10 samples in a 20 ms transient; 20 samples/cycle at 25 Hz |
| **IMU / VN-300** | **400 Hz** | **400 Hz** | **400 Hz** | Matches VN-300 specified maximum IMU output rate |
| **Brake Pressure** | **1 kHz** | **1 kHz** | **200 Hz** | 0.27 bar/sample for the 40 bar / 150 ms reference ramp |
| **Pitot Tube** | **100 Hz** | **100 Hz** | **50 Hz** | 10 ms temporal resolution with low network cost |

* * *

## 12\. Design Decision

The Datalogger does **not** use one common sampling frequency for all sensors.

The rate allocation follows:

| Step | Question | Result |
|---|---|---|
| 1. Physical behavior | What phenomenon are we measuring? | Signal characteristics |
| 2. Critical event | What is the fastest relevant event? | Required temporal resolution |
| 3. Nyquist criterion | What bandwidth must be sampled? | Minimum theoretical rate |
| 4. Sensor limitations | Can the sensor provide this rate? | Sensor constraint |
| 5. MCU limitations | Can the MCU acquire and process it? | Hardware constraint |
| 6. CAN / storage budget | Can the system transport and store the data? | System constraint |
| 7. Final rate | What rate satisfies all constraints? | Selected sampling rate |

The resulting architecture deliberately separates acquisition from communication:

```text
                       SENSOR
                         |
                         v
                High-rate acquisition
                         |
                         v
                Signal conditioning
                         |
                         v
                   Digital filter
                         |
             +-----------+-----------+
             |                       |
             v                       v
        Local logging           CAN transmission
        high-rate data          lower-rate data
```

The high-rate acquisition is retained where it provides useful information for post-test analysis. CAN transmission is reduced and packed so that the vehicle network remains deterministic.

The frequencies should be considered **engineering requirements under validation** until final sensor specifications and vehicle test data confirm them.  
'

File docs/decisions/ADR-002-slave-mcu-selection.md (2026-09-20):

# ADR-002: Slave MCU Selection

## Status

Accepted

## Context

The Datalogger Slave requires a microcontroller capable of handling:

- Sensor acquisition
- CAN FD communication
- Timer-based frequency measurement
- I2C peripherals
- ADC acquisition
- Real-time firmware execution
- Debugging through SWD

The MCU must also provide sufficient peripheral resources while keeping
the hardware complexity and cost reasonable.

## Decision

The STM32G431C8T6T**R** will be used as the main microcontroller of the
Datalogger Slave. The complete selected ordering code is
**STM32G431C8T6TR**.

## Alternatives Considered

### STM32G431C8T6TR

- CAN FD peripheral
- Multiple timers
- ADC peripherals
- I2C interfaces
- SWD debugging
- Suitable performance for the required acquisition rates

### STM32F103

Rejected because it does not provide CAN FD and has fewer resources
available for the planned architecture.

## Consequences

### Positive

- Native CAN FD support
- Sufficient timer resources
- Suitable ADC and I2C peripherals
- Good debugging support
- Keeps the Slave architecture relatively simple

### Negative

- Firmware becomes tied to the STM32G4 family
- Requires STM32-specific development tools and HAL/LL dependencies

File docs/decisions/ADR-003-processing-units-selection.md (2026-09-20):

# ADR-003: Processing Units Selection

## Status

Accepted

## Context

The Datalogger requires two processing roles with different responsibilities:

- A Master processing unit for high-level processing, data logging, telemetry, and system management.
- A Slave microcontroller for local sensor acquisition, signal processing, and CAN communication.

The selected components must be recorded as part of the project's baseline hardware definition so that hardware, firmware, and future design decisions use the same references.

## Decision

The project will use the following processing units:

| System role | Component | Abbreviation |
| --- | --- | --- |
| Master | Milk-V DUO S | MPU (Microprocessor Unit) |
| Slave | STM32G431C8T6TR | MCU (Microcontroller Unit) |

The Milk-V DUO S is responsible for the Master module's high-level processing and data-management functions. The STM32G431C8T6TR is responsible for local acquisition and processing in the Slave modules.

## Consequences

### Positive

- Establishes a single hardware reference for the Master and Slave processing units.
- Allows hardware and firmware documentation to target defined components.
- Preserves the separation between high-level processing and deterministic local acquisition.

### Negative

- The Master software and hardware integration become dependent on the Milk-V DUO S platform.
- Slave firmware and hardware become dependent on the STM32G431C8T6TR device and its development ecosystem.

## Related Decisions

- [ADR-001: Distributed Datalogger Architecture](../getting-started/ADR-001-distributed-datalogger-architecture.md)
- [ADR-002: Slave MCU Selection](../getting-started/ADR-002-slave-mcu-selection.md)

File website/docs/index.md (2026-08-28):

# Datalogger

The **Datalogger** is a distributed data acquisition and telemetry system developed for the Ampera Racing vehicle.

The system is designed to collect data from sensors distributed throughout the vehicle, process the measurements locally, and communicate the data through a reliable automotive network.

The project is divided into **Master** and **Slave** modules, allowing sensor acquisition to be distributed across the vehicle instead of concentrating all connections in a single board.

## System Overview

The Datalogger consists of:

* **Master** — central system responsible for data management, communication and higher-level processing.
* **Slave** — distributed acquisition module responsible for reading sensors and communicating with the Master.
* **CAN Network** — communication backbone between the modules.
* **Sensors** — analog, digital, frequency-based and digital-protocol sensors distributed throughout the vehicle.

```text
                    ┌───────────────┐
                    │     Master    │
                    │               │
                    └───────┬───────┘
                            │
                           CAN
                ┌───────────┴───────────┐
                │                       │
         ┌──────▼──────┐         ┌──────▼──────┐
         │   Slave 1   │         │   Slave 2   │
         │             │         │             │
         │   Sensors   │         │   Sensors   │
         └─────────────┘         └─────────────┘
```

## Documentation

The documentation is organized according to the main areas of the Datalogger system.

### Architecture

Architecture documentation describes the system design and the engineering decisions behind it.

* [Sampling Rates](architecture/sampling_rates.md)

### Hardware

Documentation related to the electronic design and PCB implementation.

> Hardware documentation is currently under development.

### Firmware

Documentation related to the embedded software running on the Datalogger modules.

> Firmware documentation is currently under development.

### Communication

Documentation related to the communication interfaces and protocols used by the Datalogger.

> Communication documentation is currently under development.

## Project Status

The Datalogger is currently under active development.

Hardware, firmware and system documentation may change as the design evolves and new requirements are established.

---

**Datalogger — Ampera Racing**

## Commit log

2026-07-22 feat(HW): create Datalogger Slave KiCad Project
    [PCB.kicad_pcb, PCB.kicad_sch]
2026-07-22 feat(HW): add shared KiCad Libraries
    [PCB.kicad_pcb, PCB.kicad_sch]
2026-07-22 feat(HW): add System Power Source Sheet
    [PCB.kicad_sch, source.kicad_sch]
2026-07-22 feat(HW): add analog input sheet
    [analog_inputs.kicad_sch]
2026-07-22 feat(HW): start control sheet implementation
    [PCB.kicad_sch, analog_inputs.kicad_sch, control.kicad_sch]
2026-07-24 feat(HW): add digital input circuit files
    [PCB.kicad_sch, analog_inputs.kicad_sch, control.kicad_sch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]
2026-07-26 refactor(HW): reduce analog inputs and update MCU analog connections
    [analog_inputs.kicad_sch, control.kicad_sch]
2026-07-28 feat(HW): add ESDALC6V1W5 component to KiCad library
2026-07-28 feat(HW): add protected high-speed and low-speed digital input circuits
    [digital_inputs.kicad_sch]
2026-07-28 refactor(HW): position adjustment
    [digital_inputs.kicad_sch]
2026-08-05 feat(HW): create communication schematic with CAN and I2C level shifter
    [PCB.kicad_sch, analog_inputs.kicad_sch, communications.kicad_sch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]
2026-08-05 feat(HW): add USB Type-C 16-pin receptacle component
2026-08-05 refactor(HW): rename components and fix reference designators
    [analog_inputs.kicad_sch, control.kicad_sch, digital_inputs.kicad_sch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]
2026-08-05 feat(HW): add USB Type-C interface
    [communications.kicad_sch]
2026-08-05 feat(HW): add footprints and configure component properties
    [analog_inputs.kicad_sch, communications.kicad_sch, control.kicad_sch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]
2026-08-06 feat(HW): start PCB design rules configuration
2026-08-06 feat(HW): add connector symbols to library
2026-08-06 feat(HW): add initial schematic pages
    [PCB.kicad_sch, communications.kicad_sch, source.kicad_sch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]
2026-08-06 feat(HW): add MCU connections
    [communications.kicad_sch, control.kicad_sch, vehicle_connections.kicad_sch]
2026-08-06 feat(CI): add KiCad ERC and DRC validation
2026-08-06 refactor(HW): update USB-C connector footprint and symbol
2026-08-06 feat(HW): add UART communication interface
    [communications.kicad_sch]
2026-08-06 refactor(HW): finalize GPIO configuration
    [control.kicad_sch]
2026-08-06 feat(HW): finalize schematic design
    [digital_inputs.kicad_sch, source.kicad_sch, vehicle_connections.kicad_sch]
2026-08-06 fix(CI): configure KiCad checks to run in container
2026-08-06 fix(CI): KiCad container permissions
2026-08-06 fix(HW): resolve ERC errors and footprint library references
    [communications.kicad_sch]
2026-08-06 refactor(CI): run KiCad checks on all hardware files
2026-08-07 fix(CI): KiCad validation loop for container shell
2026-08-07 refactor(CI): run KiCad ERC using project root schematic
2026-08-07 feat(HW): add new footprints to library
2026-08-07 fix(HW): resolve KiCad ERC warnings
    [analog_inputs.kicad_sch, control.kicad_sch, digital_inputs.kicad_sch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]
2026-08-07 fix(CI): run KiCad checks from project directory
2026-08-07 chore(CI): simplify KiCad ERC check for debugging
2026-08-07 refactor(CI): restore full KiCad project validation with custom libraries
2026-08-09 feat(DOCS): add power architecture documentation
2026-08-09 fix(DOCS): fix markdownlint errors in power architecture
2026-08-27 feat(DOCS): add sensor mapping requirements
2026-09-20 feat(DOCS): define preliminary CAN bus budget

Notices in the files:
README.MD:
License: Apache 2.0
